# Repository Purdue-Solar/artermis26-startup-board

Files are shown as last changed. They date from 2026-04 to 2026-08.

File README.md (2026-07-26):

PSR Startup Board - Artemis 2027

The purpose of this board is to activate the power distro board and indicate to the power distro board which mode of operation the car should be in. There is also a forward neutral reverse switch, which goes to the steering wheel. 

The FNR switch has three states, and each line is pulled high using an internal pullup resistor in the power distro board microcontroller. This means that the logic is inverted (if a line is driven low, it is activated).

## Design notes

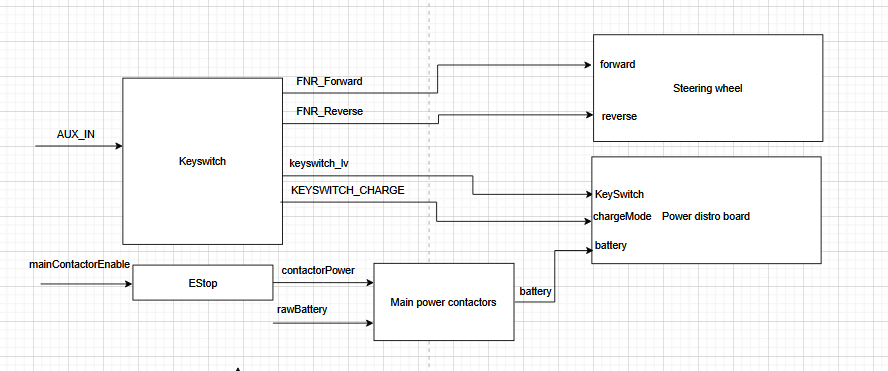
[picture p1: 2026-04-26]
images/startup.png

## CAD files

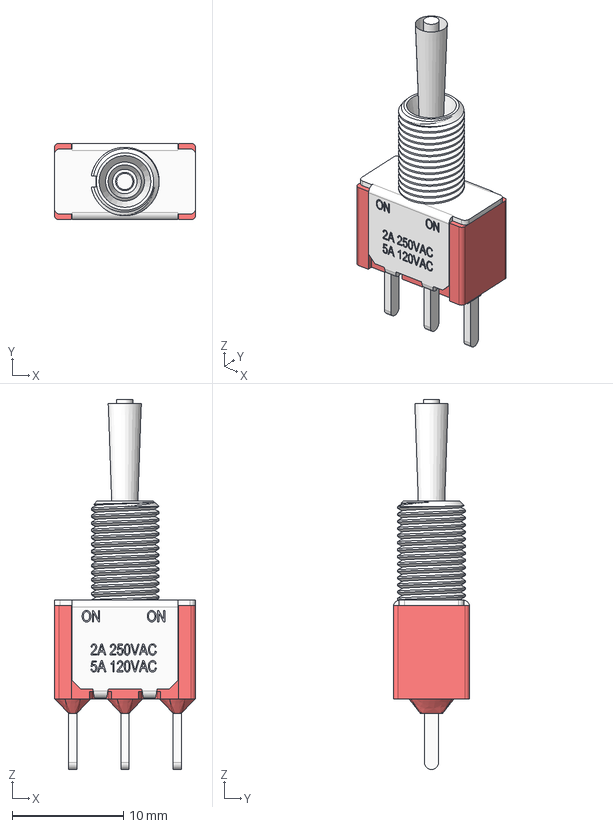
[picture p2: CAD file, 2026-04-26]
ANT13SECQE/ANT13SECQE.stp
12.7 x 6.86 x 33.3 mm
Housing_SPDT
Bushing_E
Cover_ANT11TEBQE
ANT_Actuator_S
Epoxy x 3
Terminal_C x 3

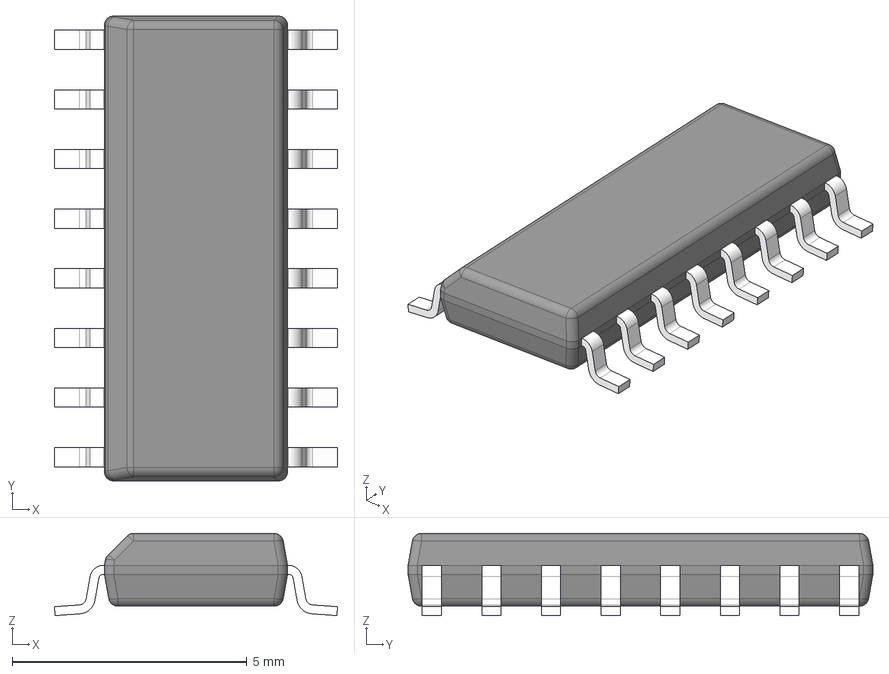
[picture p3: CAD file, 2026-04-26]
CD4049UBDR/D0016A.stp
6.03 x 9.90 x 1.75 mm
BODY-SO
LEAD-SO x 16
PIN1-ID

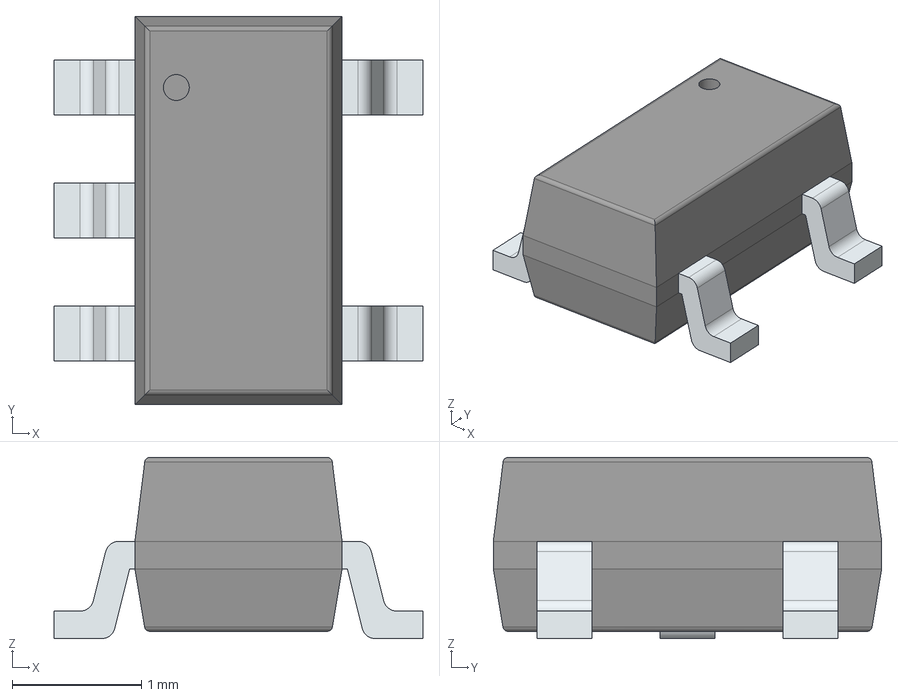
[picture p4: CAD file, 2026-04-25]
LIB_AP7380-33W5-7/AP7380-33W5-7/3D/AP7380-33W5-7.stp
2.85 x 3.00 x 1.40 mm
PinsArrayL
PinsArrayR

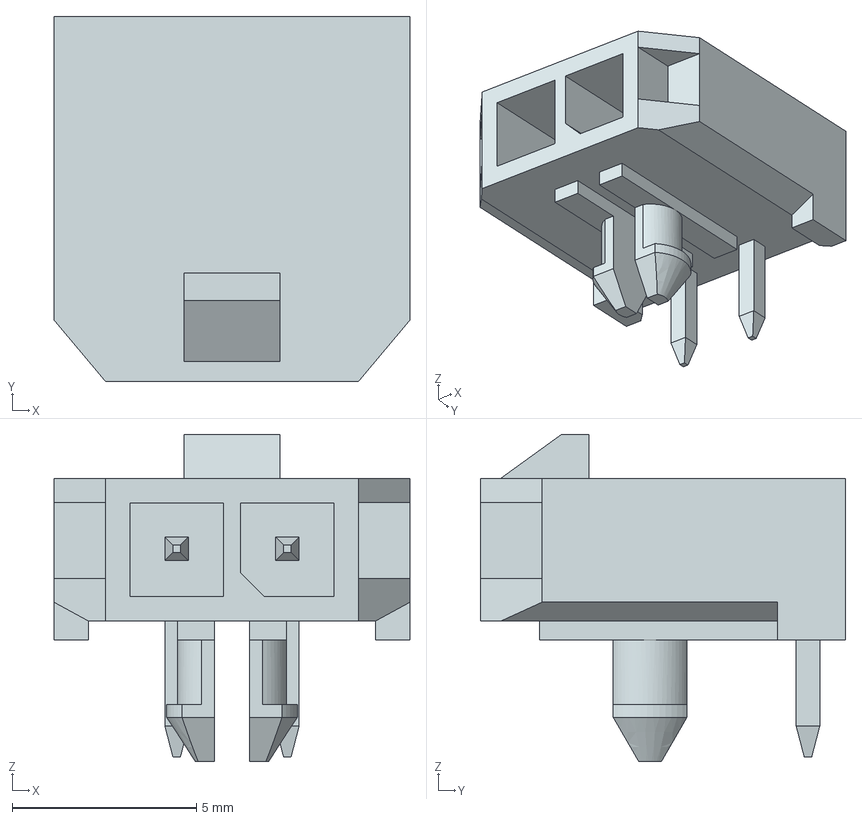
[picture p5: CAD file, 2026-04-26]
436500200/436500200.stp
9.65 x 9.90 x 8.87 mm

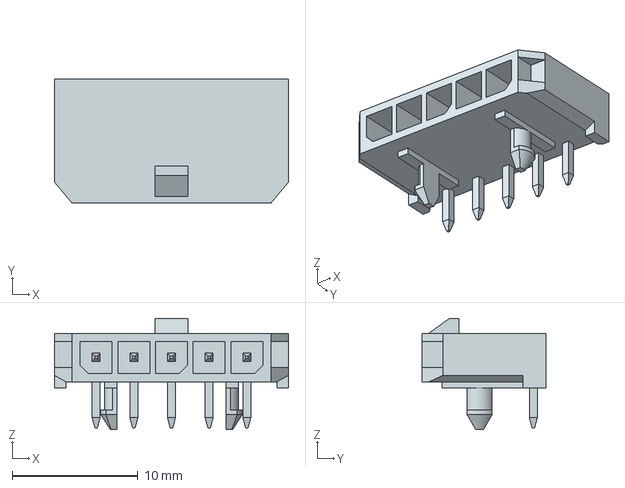
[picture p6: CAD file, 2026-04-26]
436500500/436500500.stp
18.6 x 9.90 x 8.87 mm

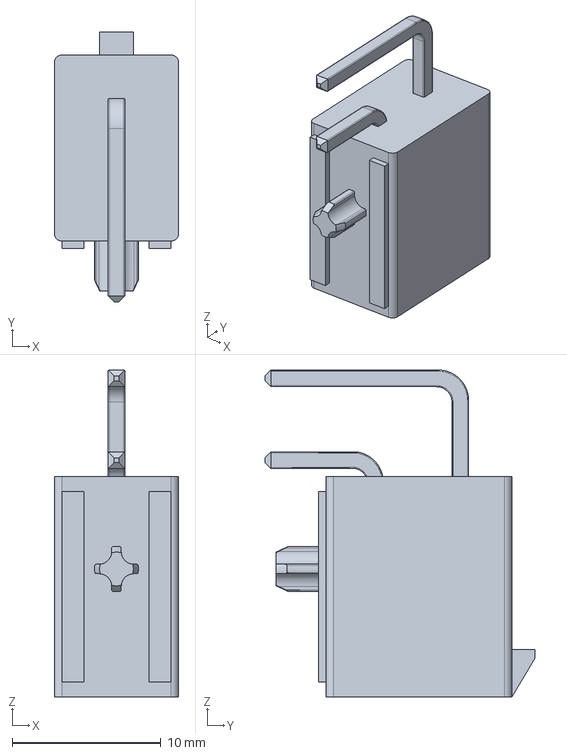
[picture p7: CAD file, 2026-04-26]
768250002/768250002.stp
8.35 x 18.1 x 22.0 mm

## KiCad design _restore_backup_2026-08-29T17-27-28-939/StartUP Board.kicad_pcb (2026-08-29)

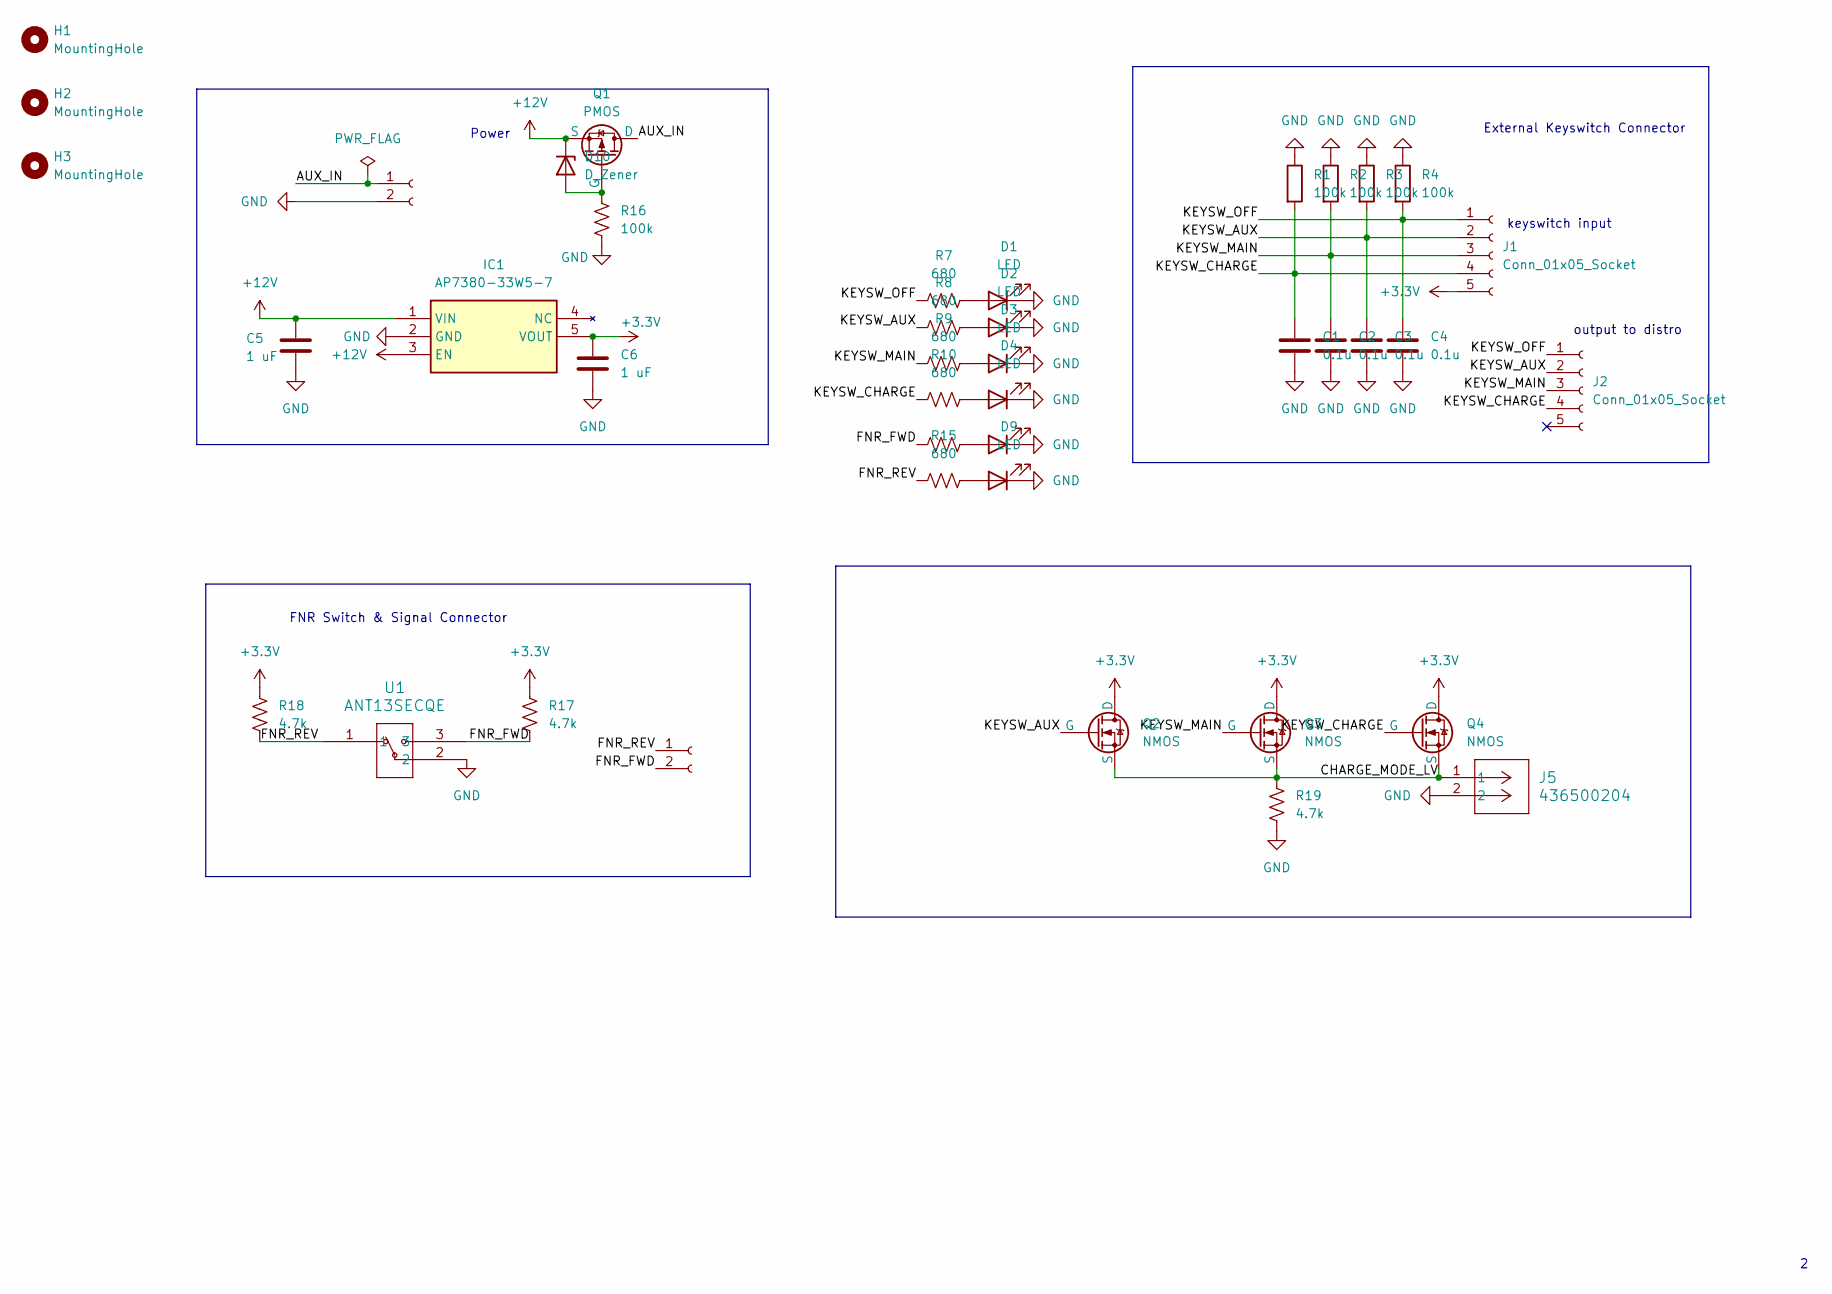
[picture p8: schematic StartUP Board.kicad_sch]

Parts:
C1, C2, C3, C4: 0.1u; C_0805_2012Metric
C5, C6: 1 uF; C_0805_2012Metric
D1, D2, D3, D4, D8, D9: LED; LED_0805_2012Metric
D10: D_Zener; D_0805_2012Metric
H1, H2, H3: MountingHole; MountingHole_3.2mm_M3
IC1: AP7380-33W5-7; Mouser Part Number 621-AP7380-33W5-7
J1, J2: Conn_01x05_Socket; Molex_Micro-Fit_3.0_43650-0500_1x05_P3.00mm_Horizontal
J3: Molex_Micro-Fit_3.0_43650-0200_1x02_P3.00mm_Horizontal
J4: Molex_Mega-Fit_76825-0002_2x01_P5.70mm_Horizontal
J5: 436500204; CONN_SD-43650-002_02_MOL
Q1: PMOS; TSOT-23
Q2, Q3, Q4: NMOS; TSOT-23
R1, R2, R3, R4, R16: 100k; R_0805_2012Metric
R7, R8, R9, R10, R14, R15: 680; R_0805_2012Metric
R17, R18, R19: 4.7k; R_0805_2012Metric
U1: ANT13SECQE; ANT13SEC_CRS

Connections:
+3.3V: C6.1, IC1.5 (VOUT), J1.5, Q2.1 (D), Q3.1 (D), Q4.1 (D), R17.2, R18.2
+12V: C5.1, D10.1 (K), IC1.1 (VIN), IC1.3 (EN), Q1.3 (S)
/AUX_IN: J4.1, Q1.1 (D)
/CHARGE_MODE_LV: J5.1, Q2.3 (S), Q3.3 (S), Q4.3 (S), R19.2
/FNR_FWD: J3.2, R14.1, R17.1, U1.3
/FNR_REV: J3.1, R15.1, R18.1, U1.1
/KEYSW_AUX: C3.1, J1.2, J2.2, Q2.2 (G), R3.2, R8.1
/KEYSW_CHARGE: C1.1, J1.4, J2.4, Q4.2 (G), R1.2, R10.1
/KEYSW_MAIN: C2.1, J1.3, J2.3, Q3.2 (G), R2.2, R9.1
/KEYSW_OFF: C4.1, J1.1, J2.1, R4.2, R7.1
GND: C1.2, C2.2, C3.2, C4.2, C5.2, C6.2, D1.1 (K), D2.1 (K), D3.1 (K), D4.1 (K), D8.1 (K), D9.1 (K), IC1.2 (GND), J4.2, J5.2, R1.1, R2.1, R3.1, R4.1, R16.1, R19.1, U1.2
unnamed: D1.2 (A), R7.2
unnamed: D2.2 (A), R8.2
unnamed: D3.2 (A), R9.2
unnamed: D4.2 (A), R10.2
unnamed: D8.2 (A), R14.2
unnamed: D9.2 (A), R15.2
unnamed: D10.2 (A), Q1.2 (G), R16.2

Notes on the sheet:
Power
keyswitch input
FNR Switch & Signal Connector
External Keyswitch Connector
output to distro

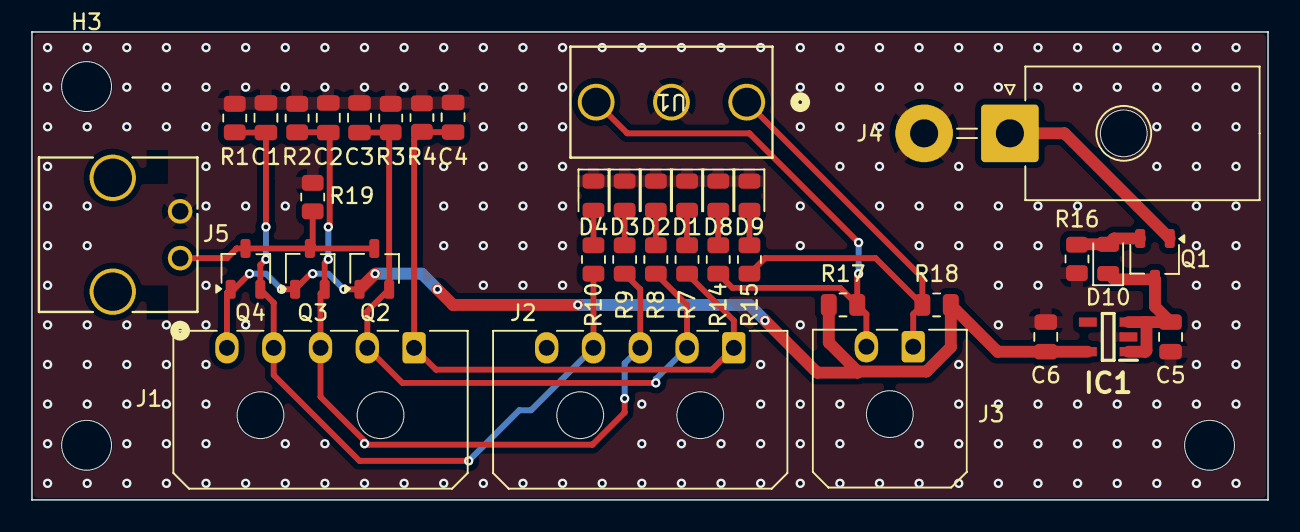
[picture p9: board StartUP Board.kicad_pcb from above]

Board: 2 copper layers, 79.2 x 30.0 mm, 41 parts (0 on the bottom side), 18 nets.

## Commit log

2025-07-26 pcb board progress, schematic should be finalized
    [StartUP Board.kicad_pcb]
2025-08-01 Updated PCB layout, added mounting holes
    [StartUP Board.kicad_pcb]
2025-08-01 moved connectors to the bottom of the pcb, should be mostly finished
    [StartUP Board.kicad_pcb]
2026-03-07 revised start up board 3-7-26
    [StartUP Board.kicad_pcb, StartUP Board.kicad_sch]
2026-03-07 Revised start up board, hopefully done
    [StartUP Board.kicad_pcb, StartUP Board.kicad_sch]
2026-03-08 Man added
    [StartUP Board.csv, StartUP Board.kicad_pcb, StartUP Board.kicad_sch]
2026-04-25 upload vivian iteration of PCB
    [AP7380-33W5-7.SchLib, AP7380-33W5-7.stp, BSS159NH6327XTSA2.step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]
2026-04-25 Clean up repo: add .gitignore, remove 248 junk files
    - Renamed KiCad.gitignore → .gitignore (was never active before)
    - Added rules for *.step, fabrication-toolkit-options.json, production/backups/, artermis26-startup-board-main/
    - Removed from tracking: auto-backups, lock files, autorouter exports, BOM CSVs, fp-info-cache, 3D STEP exports, the accidentally-committed duplicate repo zip, and all non-KiCad EDA tool format files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
    [AP7380-33W5-7.SchLib, AP7380-33W5-7.stp, BSS159NH6327XTSA2.step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]
2026-04-26 add step files
    [436500200.stp, 436500500.stp, 768250002.stp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]
